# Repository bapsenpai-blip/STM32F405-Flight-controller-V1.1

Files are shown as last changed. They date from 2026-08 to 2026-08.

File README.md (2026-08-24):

# STM32F405-Flight-controller-V1.1
After the freaking horrible v1, I have changed a lot to improve my FC as much as possible.
RealFCv1 1
RealFCv1 1-back

### Changes from the V1
- Remove the SD card slot (took too much space). Using a blackbox instead.
- Remove 1 USB-C connector for ESP32. Now using an usb-mux + slide switch to choose which MCU is connected.
- Cleaner layout, board size changed from freaking big to 50x50mm (30.5x30.5 mounting hole).

### Components
- STM32F405RGT6: doing the basic things of an FC (calculate angles, PID, motor mixer,...)
- ESP32 S3 - WROOM 02: using DroneBrigde method for affordable Telemetry (I have no money to buy an $60 MAVLink Telemetry module)
- 8MHz Crystals from China: 10pF CLoad
- IMU: ICM-20602
- Barometer: BMP280
- Flash Memory: W25Q128JVS (16MB SPI Flash for Blackbox logging)
- USB-C Receptable 2.0 16 pins
- FSUSB42MUX: combining with a slideswitch to change the USB signal to desired MCU.
- Power supply: I'm gonna use an external Buck Converter, because I have no idea about power electronics
- USBLC6-2SC6: ESD protection for USB-C
- 2 AP2112K-3.3Vs: one for STM32 and other main components, one for only ESP32 (ESP32 consumes a lot of current when using Wi-fi/BLE)
- 2 SS14 Diodes: preventing reverse currents
- Resistors and capacitors: based on the recommendation of components' datasheets.

### Pin Mapping & Peripheral Connections

| Peripheral / Interface | Signal Name | MCU Pin | Description / Target |
| :--- | :--- | :--- | :--- |
| **IMU (ICM-20602)** | SPI2_NSS / SCK / MISO / MOSI | `PB12` / `PB13` / `PB14` / `PB15` | SPI Sensor Bus |
| | IMU_DDRY | `PC6` | EXTI Data Ready Interrupt |
| **Blackbox (W25Q128)** | SPI1_NSS / SCK / MISO / MOSI | `PA4` / `PA5` / `PA6` / `PA7` | 16MB SPI NOR Flash |
| **Barometer (BMP280)** | I2C1_SCL / I2C1_SDA | `PB8` / `PB9` | Internal Baro (4.7kΩ pull-ups) |
| **Motors (DSHOT)** | DSHOT_CH1 / CH2 | `PB4` / `PB5` | TIM3_CH1, TIM3_CH2 (to J3 ESC) |
| | DSHOT_CH3 / CH4 | `PB6` / `PB7` | TIM4_CH1, TIM4_CH4 (to J3 ESC) |
| **Telemetry (ESP32-S3)** | UART3_TX / UART3_RX | `PB10` / `PB11` | DroneBridge Telemetry link |
| **RC Receiver (J4)** | UART1_TX / UART1_RX | `PA9` / `PA10` | Serial RX (CRSF / SBUS / IBUS) |
| **GPS / Ext Sensor (J5)** | UART2_TX / UART2_RX | `PA2` / `PA3` | External GPS Serial Port |
| | I2C1_SCL / I2C1_SDA | `PB8` / `PB9` | External Compass / Sensor Bus |
| **ESC Telemetry (J3)** | UART4_RX | `PA1` | ESC Telemetry feedback |
| **Current / Voltage Sensing**| ADC1_IN14 (CURR) | `PC4` | Current sensor via 1kΩ / 100nF filter |
| | ADC1_IN15 (VBAT) | `PC5` | Battery voltage via 10:1 divider (11x) |
| **Status LEDs** | STAT_LED1 / LED2 / LED3 | `PC14` / `PB3` / `PC13` | Debug & status indicators |
| **USB & Debug (J7)** | S_D- / S_D+ | `PA11` / `PA12` | USB FS (via FSUSB42 MUX) |
| | SWDIO / SWCLK | `PA13` / `PA14` | SWD Debug port |

### Status & Firmware
- [x] Hardware verification: Validated on a custom STM32F405 breakout board (SPI, I2C, UART peripherals verified and working stably).
- [x] V1.1 PCB design & layout completed (ready for manufacturing/bring-up).
- [ ] Bring-up V1.1 integrated board (test power rails, USB mux swiSching, and onboard sensors).
- [ ] Port and configure open-source flight firmware (Betaflight / INAV / ArduPilot target).
- [ ] Bring-up ESP32-CS DroneBridge telemetry link.
- [ ] Bench test with 4-in-1 ESC (DShot) & maiden flight test.

**Firmware & Tools:** 
- Open-source flight controller firmware (target bring-up)
- ESP-IDF / DroneBridge for ESP32-S3
- VS Code - PlatformIO for low-level validation & debugging

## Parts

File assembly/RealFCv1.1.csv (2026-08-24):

Reference | Qty | Value | DNP | Exclude from BOM | Exclude from Board | Footprint | Datasheet
+VIN_BEC1,-VIN_BEC1 | 2 | TestPoint |  |  |  | TestPoint:TestPoint_THTPad_3.0x3.0mm_Drill1.5mm
C1,C2,C3,C4,C5,C7,C8,C14,C18,C20,C21,C22,C23,C24,C29,C30,C31,C32 | 18 | 100nF |  |  |  | Capacitor_SMD:C_0402_1005Metric_Pad0.74x0.62mm_HandSolder
C9,C10 | 2 | 12pF |  |  |  | Capacitor_SMD:C_0402_1005Metric_Pad0.74x0.62mm_HandSolder
C11,C12,C15 | 3 | 2.2uF |  |  |  | Capacitor_SMD:C_0402_1005Metric_Pad0.74x0.62mm_HandSolder
C13,C16,C25,C26 | 4 | 1uF |  |  |  | Capacitor_SMD:C_0402_1005Metric_Pad0.74x0.62mm_HandSolder
C17 | 1 | 4.7uF |  |  |  | Capacitor_SMD:C_0805_2012Metric_Pad1.18x1.45mm_HandSolder
C19 | 1 | 10nF |  |  |  | Capacitor_SMD:C_0402_1005Metric_Pad0.74x0.62mm_HandSolder
C27 | 1 | 4.7u |  |  |  | Capacitor_SMD:C_0805_2012Metric_Pad1.18x1.45mm_HandSolder
C28 | 1 | 10uF |  |  |  | Capacitor_SMD:C_0603_1608Metric_Pad1.08x0.95mm_HandSolder
D2,D5,D8,D12 | 4 | LED_RED |  |  |  | LED_SMD:LED_0402_1005Metric_Pad0.77x0.64mm_HandSolder
D3,D4 | 2 | SS14 |  |  |  | Diode_SMD:D_SMA | https://www.vishay.com/docs/88746/ss12.pdf
J1 | 1 | USB_C_Receptacle_USB2.0_14P |  |  |  | Connector_USB:USB_C_Receptacle_HRO_TYPE-C-31-M-12 | https://www.usb.org/sites/default/files/documents/usb_type-c.zip
J3 | 1 | Conn_01x08_Socket |  |  |  | Connector_JST:JST_SH_SM08B-SRSS-TB_1x08-1MP_P1.00mm_Horizontal
J4 | 1 | Conn_01x04_Socket |  |  |  | Connector_JST:JST_SH_SM04B-SRSS-TB_1x04-1MP_P1.00mm_Horizontal
J5 | 1 | Conn_01x06_Socket |  |  |  | Connector_JST:JST_SH_SM06B-SRSS-TB_1x06-1MP_P1.00mm_Horizontal
J7 | 1 | Conn_01x04_Socket |  |  |  | Connector_PinHeader_2.54mm:PinHeader_1x04_P2.54mm_Vertical
R2,R3,R17,R24,R25,R26 | 6 | 10kR |  |  |  | Resistor_SMD:R_0402_1005Metric_Pad0.72x0.64mm_HandSolder
R4,R5 | 2 | 5.1kR |  |  |  | Resistor_SMD:R_0402_1005Metric_Pad0.72x0.64mm_HandSolder
R7,R8,R14,R15,R16,R29 | 6 | 1kR |  |  |  | Resistor_SMD:R_0402_1005Metric_Pad0.72x0.64mm_HandSolder
R10,R11,R18,R19,R20 | 5 | 4.7kR |  |  |  | Resistor_SMD:R_0402_1005Metric_Pad0.72x0.64mm_HandSolder
SW1,SW2 | 2 | SW_Push |  |  |  | Button_Switch_SMD:SW_Push_1P1T-SH_NO_CK_KMR2xxG
SW5 | 1 | SW_SPDT_312 |  |  |  | Button_Switch_SMD:SW_SPDT_PCM12
TP1,TP2,TP3,TP4 | 4 | TestPoint |  |  |  | TestPoint:TestPoint_Pad_D1.0mm
U1 | 1 | STM32F405RGTx |  |  |  | Package_QFP:LQFP-64_10x10mm_P0.5mm | https://www.st.com/resource/en/datasheet/stm32f405rg.pdf
U2,U7 | 2 | AP2112K-3.3 |  |  |  | Package_TO_SOT_SMD:SOT-23-5_HandSoldering | https://www.diodes.com/assets/Datasheets/AP2112.pdf
U3 | 1 | USBLC6-2SC6 |  |  |  | Package_TO_SOT_SMD:SOT-23-6_Handsoldering | https://www.st.com/resource/en/datasheet/usblc6-2.pdf
U4 | 1 | ICM-20602 |  |  |  | Package_LGA:LGA-16_3x3mm_P0.5mm_LayoutBorder3x5y | http://www.invensense.com/wp-content/uploads/2016/10/DS-000176-ICM-20602-v1.0.pdf
U5 | 1 | BMP280 |  |  |  | Package_LGA:Bosch_LGA-8_2x2.5mm_P0.65mm_ClockwisePinNumbering | https://ae-bst.resource.bosch.com/media/_tech/media/datasheets/BST-BMP280-DS001.pdf
U6 | 1 | ESP32-C3-WROOM-02 |  |  |  | RF_Module:ESP32-C3-WROOM-02 | https://www.espressif.com/sites/default/files/documentation/esp32-c3-wroom-02_datasheet_en.pdf
U9 | 1 | W25Q128JVS |  |  |  | Package_SO:SOIC-8_5.3x5.3mm_P1.27mm | https://www.winbond.com/resource-files/w25q128jv_dtr%20revc%2003272018%20plus.pdf
U10 | 1 | FSUSB42MUX |  |  |  | Package_SO:MSOP-10_3x3mm_P0.5mm | https://www.onsemi.com/pub/Collateral/FSUSB42-D.PDF
Y1 | 1 | Crystal_GND24 |  |  |  | Crystal:Crystal_SMD_3225-4Pin_3.2x2.5mm_HandSoldering

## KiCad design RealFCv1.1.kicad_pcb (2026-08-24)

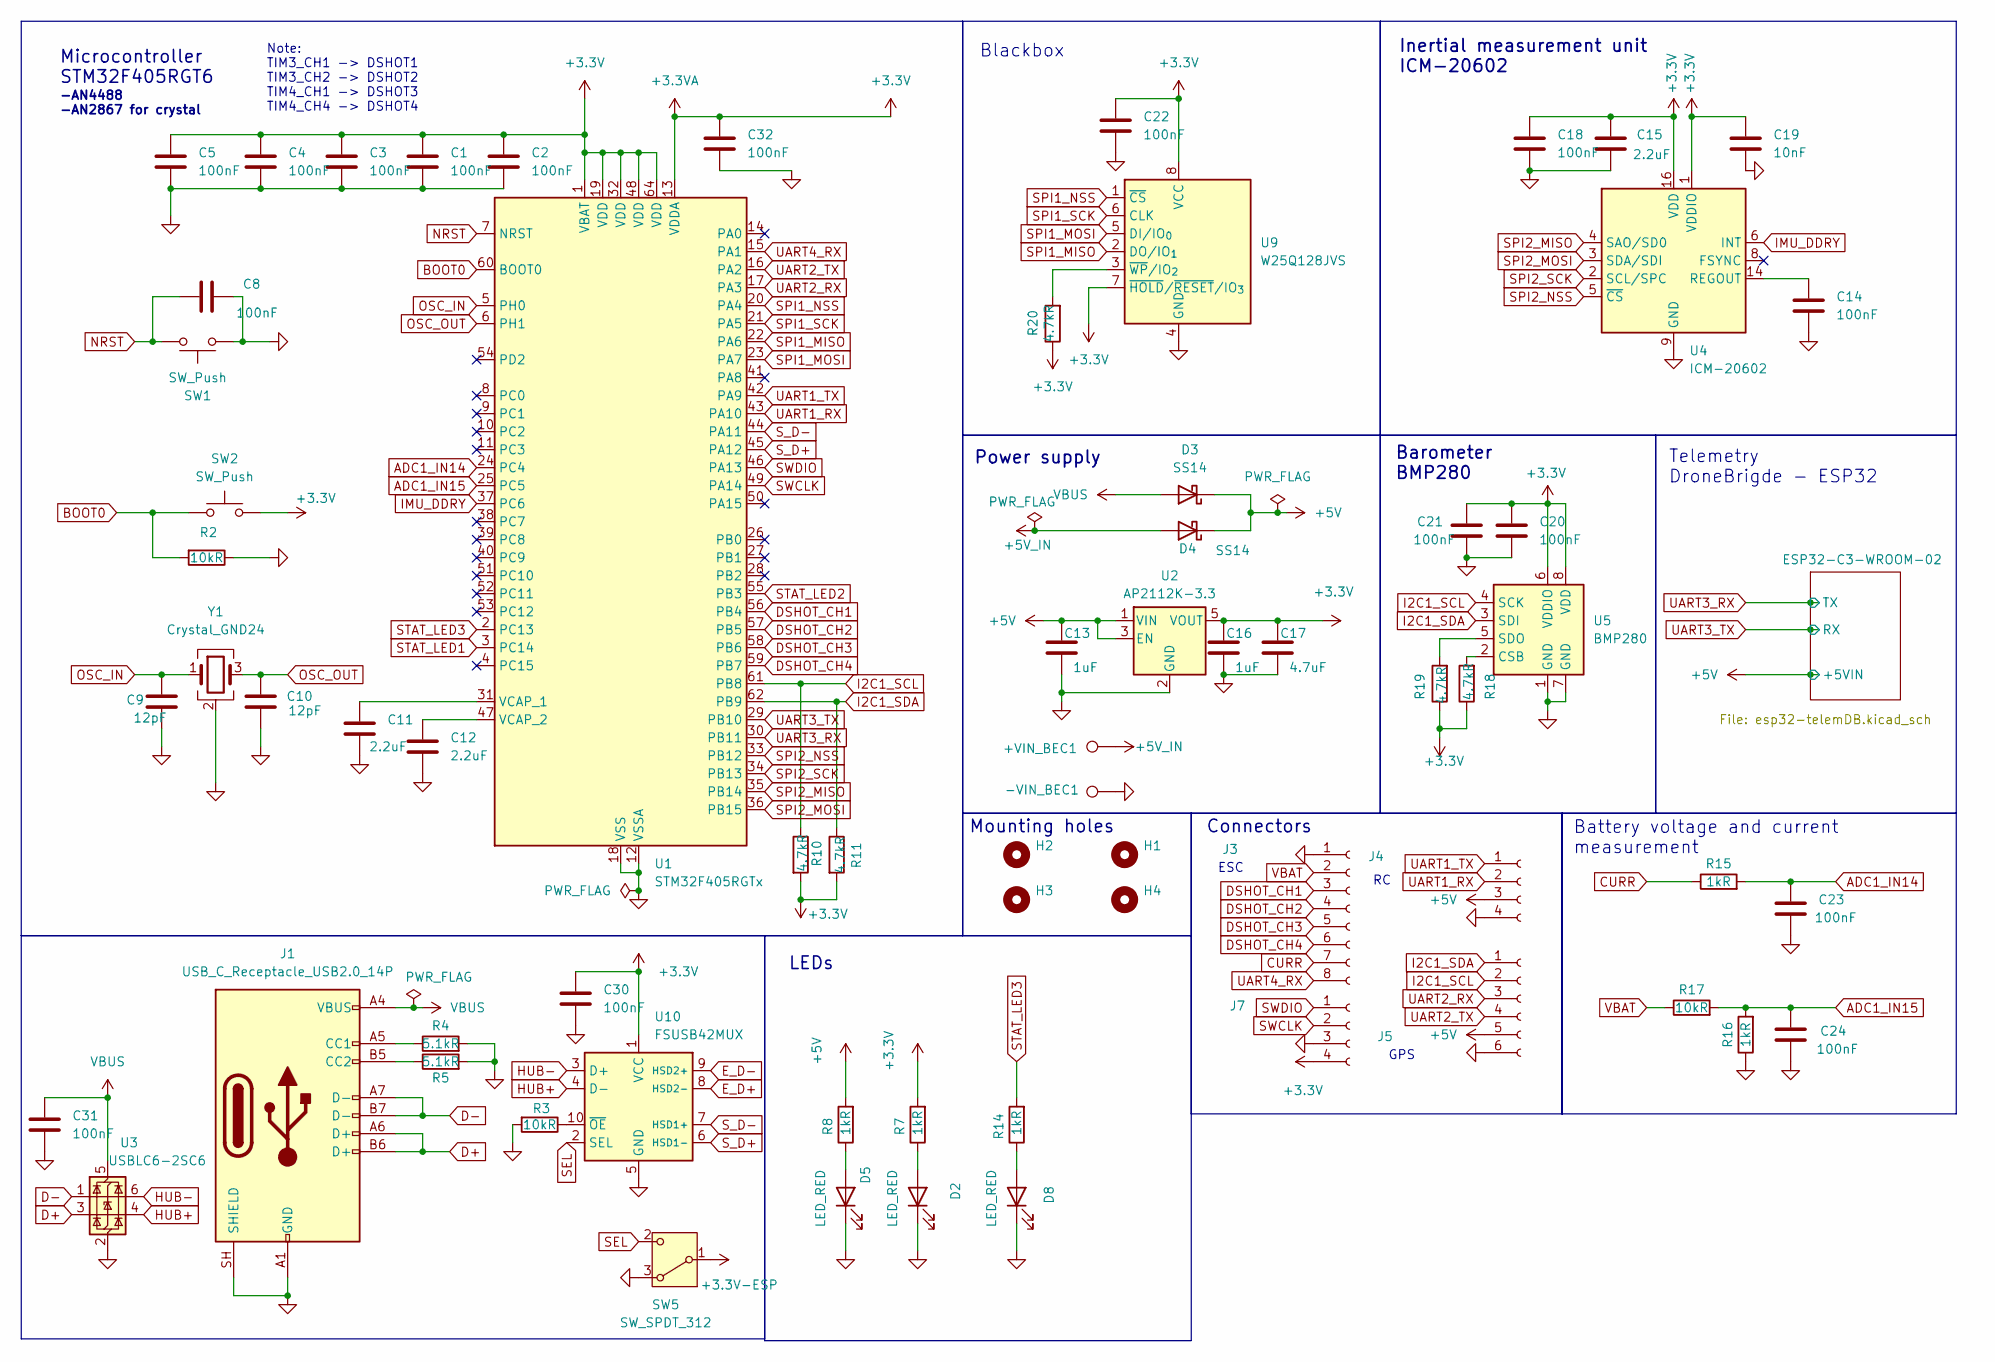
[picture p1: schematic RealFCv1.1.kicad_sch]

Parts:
+VIN_BEC1: TestPoint; TestPoint_THTPad_3.0x3.0mm_Drill1.5mm
-VIN_BEC1: TestPoint; TestPoint_THTPad_3.0x3.0mm_Drill1.5mm
C1, C2, C3, C4, C5, C8, C14, C18, C20, C21, C22, C23, C24, C30, C31, C32: 100nF; C_0402_1005Metric_Pad0.74x0.62mm_HandSolder
C9, C10: 12pF; C_0402_1005Metric_Pad0.74x0.62mm_HandSolder
C11, C12, C15: 2.2uF; C_0402_1005Metric_Pad0.74x0.62mm_HandSolder
C13, C16: 1uF; C_0402_1005Metric_Pad0.74x0.62mm_HandSolder
C17: 4.7uF; C_0805_2012Metric_Pad1.18x1.45mm_HandSolder
C19: 10nF; C_0402_1005Metric_Pad0.74x0.62mm_HandSolder
D2, D5, D8: LED_RED; LED_0402_1005Metric_Pad0.77x0.64mm_HandSolder
D3, D4: SS14; D_SMA
H1, H2, H3, H4: MountingHole; MountingHole_3.2mm_M3
J1: USB_C_Receptacle_USB2.0_14P; USB_C_Receptacle_HRO_TYPE-C-31-M-12
J3: Conn_01x08_Socket; JST_SH_SM08B-SRSS-TB_1x08-1MP_P1.00mm_Horizontal
J4: Conn_01x04_Socket; JST_SH_SM04B-SRSS-TB_1x04-1MP_P1.00mm_Horizontal
J5: Conn_01x06_Socket; JST_SH_SM06B-SRSS-TB_1x06-1MP_P1.00mm_Horizontal
J7: Conn_01x04_Socket; PinHeader_1x04_P2.54mm_Vertical
R2, R3, R17: 10kR; R_0402_1005Metric_Pad0.72x0.64mm_HandSolder
R4, R5: 5.1kR; R_0402_1005Metric_Pad0.72x0.64mm_HandSolder
R7, R8, R14, R15, R16: 1kR; R_0402_1005Metric_Pad0.72x0.64mm_HandSolder
R10, R11, R18, R19, R20: 4.7kR; R_0402_1005Metric_Pad0.72x0.64mm_HandSolder
SW1, SW2: SW_Push; SW_Push_1P1T-SH_NO_CK_KMR2xxG
SW5: SW_SPDT_312; SW_SPDT_PCM12
U1: STM32F405RGTx; LQFP-64_10x10mm_P0.5mm
U2: AP2112K-3.3; SOT-23-5_HandSoldering
U3: USBLC6-2SC6; SOT-23-6_Handsoldering
U4: ICM-20602; LGA-16_3x3mm_P0.5mm_LayoutBorder3x5y
U5: BMP280; Bosch_LGA-8_2x2.5mm_P0.65mm_ClockwisePinNumbering
U9: W25Q128JVS; SOIC-8_5.3x5.3mm_P1.27mm
U10: FSUSB42MUX; MSOP-10_3x3mm_P0.5mm
Y1: Crystal_GND24; Crystal_SMD_3225-4Pin_3.2x2.5mm_HandSoldering

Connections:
+3.3V: C1.1, C2.1, C3.1, C4.1, C5.1, C15.1, C16.1, C17.1, C18.1, C19.1, C20.1, C21.1, C22.2, C30.2, C32.1, J7.4, R7.2, R10.2, R11.2, R18.1, R19.1, R20.1, SW2.2, U1.1 (VBAT), U1.13 (VDDA), U1.19 (VDD), U1.32 (VDD), U1.48 (VDD), U1.64 (VDD), U2.5 (VOUT), U4.1 (VDDIO), U4.16 (VDD), U5.6 (VDDIO), U5.8 (VDD), U9.7 (~HOLD/~RESET/IO_{3}), U9.8 (VCC), U10.1 (VCC)
+3.3V-ESP: SW5.1 (B); also elsewhere on the board
+5V: C13.1, D3.1 (K), D4.1 (K), J4.3, J5.5, R8.2, U2.1 (VIN), U2.3 (EN); also elsewhere on the board
+5V_IN: +VIN_BEC1.1 (1_1), D4.2 (A)
ADC1_IN14: C23.1, R15.2, U1.24 (PC4)
ADC1_IN15: C24.1, R16.2, R17.2, U1.25 (PC5)
BOOT0: R2.2, SW2.1, U1.60 (BOOT0)
CURR: J3.7, R15.1
D+: J1.A6 (D+), J1.B6 (D+), U3.3 (I/O2)
D-: J1.A7 (D-), J1.B7 (D-), U3.1 (I/O1)
DSHOT_CH1: J3.3, U1.56 (PB4)
DSHOT_CH2: J3.4, U1.57 (PB5)
DSHOT_CH3: J3.5, U1.58 (PB6)
DSHOT_CH4: J3.6, U1.59 (PB7)
E_D+: U10.8 (HSD2-); also elsewhere on the board
E_D-: U10.9 (HSD2+); also elsewhere on the board
GND: -VIN_BEC1.1 (1_1), C1.2, C2.2, C3.2, C4.2, C5.2, C8.2, C9.2, C10.2, C11.2, C12.2, C13.2, C14.2, C15.2, C16.2, C17.2, C18.2, C19.2, C20.2, C21.2, C22.1, C23.2, C24.2, C30.1, C31.1, C32.2, D2.1 (K), D5.1 (K), D8.1 (K), J1.A1 (GND), J1.A12 (GND), J1.B1 (GND), J1.B12 (GND), J1.SH (SHIELD), J3.1, J4.4, J5.6, J7.3, R2.1, R3.2, R4.2, R5.2, R16.1, SW1.1, SW5.3 (A), U1.12 (VSSA), U1.18 (VSS), U1.63 (VSS), U2.2 (GND), U3.2 (GND), U4.9 (GND), U4.10 (GND), U4.11 (GND), U4.12 (GND), U4.13 (GND), U4.15 (GND), U5.1 (GND), U5.7 (GND), U9.4 (GND), U10.5 (GND), Y1.2 (G), Y1.4 (G); also elsewhere on the board
HUB+: U3.4 (I/O2), U10.4 (D-)
HUB-: U3.6 (I/O1), U10.3 (D+)
I2C1_SCL: J5.2, R10.1, U1.61 (PB8), U5.4 (SCK)
I2C1_SDA: J5.1, R11.1, U1.62 (PB9), U5.3 (SDI)
IMU_DDRY: U1.37 (PC6), U4.6 (INT)
NRST: C8.1, SW1.2, U1.7 (NRST)
unnamed: D2.2 (A), R7.1
unnamed: D5.2 (A), R8.1
unnamed: D8.2 (A), R14.1
unnamed: J1.A5 (CC1), R4.1
unnamed: J1.B5 (CC2), R5.1
unnamed: C11.1, U1.31 (VCAP_1)
unnamed: C12.1, U1.47 (VCAP_2)
unnamed: C14.1, U4.14 (REGOUT)
unnamed: R18.2, U5.2 (CSB)
unnamed: R19.2, U5.5 (SDO)
unnamed: R20.2, U9.3 (~WP/IO_{2})
unnamed: R3.1, U10.10 (~OE)
OSC_IN: C9.1, U1.5 (PH0), Y1.1
OSC_OUT: C10.1, U1.6 (PH1), Y1.3
SEL: SW5.2 (C), U10.2 (SEL)
SPI1_MISO: U1.22 (PA6), U9.2 (DO/IO_{1})
SPI1_MOSI: U1.23 (PA7), U9.5 (DI/IO_{0})
SPI1_NSS: U1.20 (PA4), U9.1 (~CS)
SPI1_SCK: U1.21 (PA5), U9.6 (CLK)
SPI2_MISO: U1.35 (PB14), U4.4 (SAO/SD0)
SPI2_MOSI: U1.36 (PB15), U4.3 (SDA/SDI)
SPI2_NSS: U1.33 (PB12), U4.5 (~CS)
SPI2_SCK: U1.34 (PB13), U4.2 (SCL/SPC)
STAT_LED1: U1.3 (PC14)
STAT_LED2: U1.55 (PB3)
STAT_LED3: R14.2, U1.2 (PC13)
SWCLK: J7.2, U1.49 (PA14)
SWDIO: J7.1, U1.46 (PA13)
S_D+: U1.45 (PA12), U10.6 (HSD1-)
S_D-: U1.44 (PA11), U10.7 (HSD1+)
UART1_RX: J4.2, U1.43 (PA10)
UART1_TX: J4.1, U1.42 (PA9)
UART2_RX: J5.3, U1.17 (PA3)
UART2_TX: J5.4, U1.16 (PA2)
UART3_RX: U1.30 (PB11); also elsewhere on the board
UART3_TX: U1.29 (PB10); also elsewhere on the board
UART4_RX: J3.8, U1.15 (PA1)
VBAT: J3.2, R17.1
VBUS: C31.2, D3.2 (A), J1.A4 (VBUS), J1.A9 (VBUS), J1.B4 (VBUS), J1.B9 (VBUS), U3.5 (VBUS)

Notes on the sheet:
Microcontroller STM32F405RGT6
Note: TIM3_CH1 -> DSHOT1 TIM3_CH2 -> DSHOT2 TIM4_CH1 -> DSHOT3 TIM4_CH4 -> DSHOT4
ESC
Telemetry DroneBrigde - ESP32
Inertial measurement unit ICM-20602
GPS
Barometer BMP280
Power supply
LEDs
Blackbox
Battery voltage and current measurement
Mounting holes
Connectors
-AN4488 -AN2867 for crystal

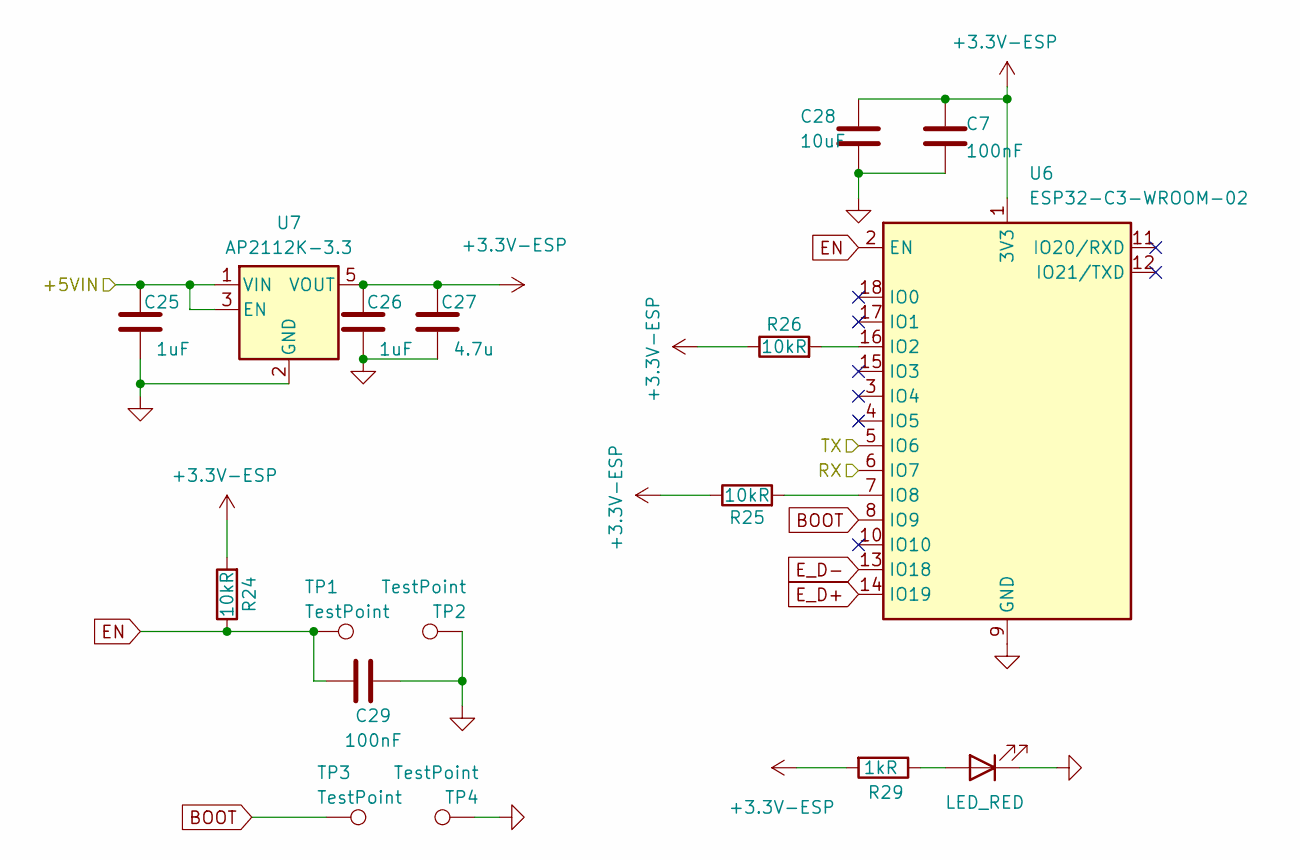
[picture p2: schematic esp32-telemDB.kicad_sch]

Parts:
C7, C29: 100nF; C_0402_1005Metric_Pad0.74x0.62mm_HandSolder
C25, C26: 1uF; C_0402_1005Metric_Pad0.74x0.62mm_HandSolder
C27: 4.7u; C_0805_2012Metric_Pad1.18x1.45mm_HandSolder
C28: 10uF; C_0603_1608Metric_Pad1.08x0.95mm_HandSolder
D12: LED_RED; LED_0402_1005Metric_Pad0.77x0.64mm_HandSolder
R24, R25, R26: 10kR; R_0402_1005Metric_Pad0.72x0.64mm_HandSolder
R29: 1kR; R_0402_1005Metric_Pad0.72x0.64mm_HandSolder
TP1, TP2, TP3, TP4: TestPoint; TestPoint_Pad_D1.0mm
U6: ESP32-C3-WROOM-02
U7: AP2112K-3.3; SOT-23-5_HandSoldering

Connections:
+3.3V-ESP: C7.1, C26.1, C27.1, C28.1, R24.2, R25.1, R26.1, R29.2, U6.1 (3V3), U7.5 (VOUT); also elsewhere on the board
+5V: C25.1, U7.1 (VIN), U7.3 (EN); also elsewhere on the board
BOOT: TP3.1 (1_1), U6.8 (IO9)
EN: C29.1, R24.1, TP1.1 (1_1), U6.2 (EN)
E_D+: U6.14 (IO19); also elsewhere on the board
E_D-: U6.13 (IO18); also elsewhere on the board
GND: C7.2, C25.2, C26.2, C27.2, C28.2, C29.2, D12.1 (K), TP2.1 (1_1), TP4.1 (1_1), U6.9 (GND), U6.19 (GND), U7.2 (GND); also elsewhere on the board
unnamed: D12.2 (A), R29.1
unnamed: R26.2, U6.16 (IO2)
unnamed: R25.2, U6.7 (IO8)
UART3_RX: U6.5 (IO6); also elsewhere on the board
UART3_TX: U6.6 (IO7); also elsewhere on the board

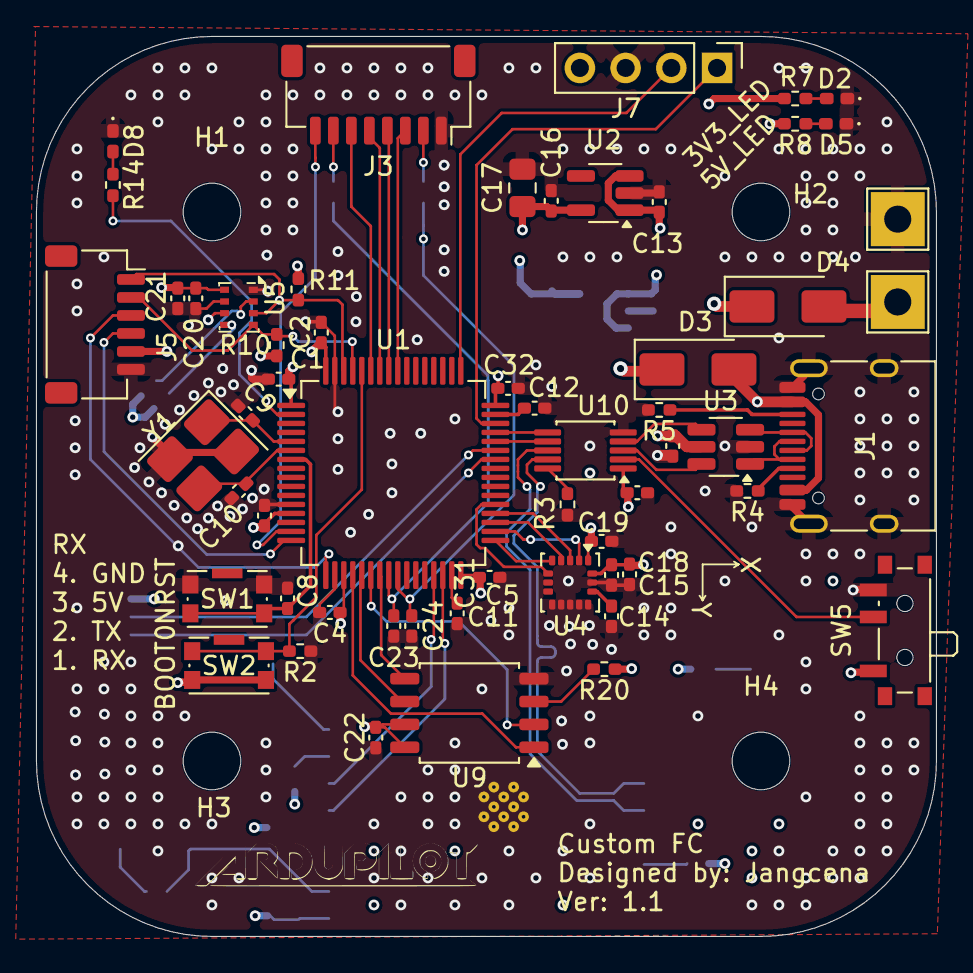
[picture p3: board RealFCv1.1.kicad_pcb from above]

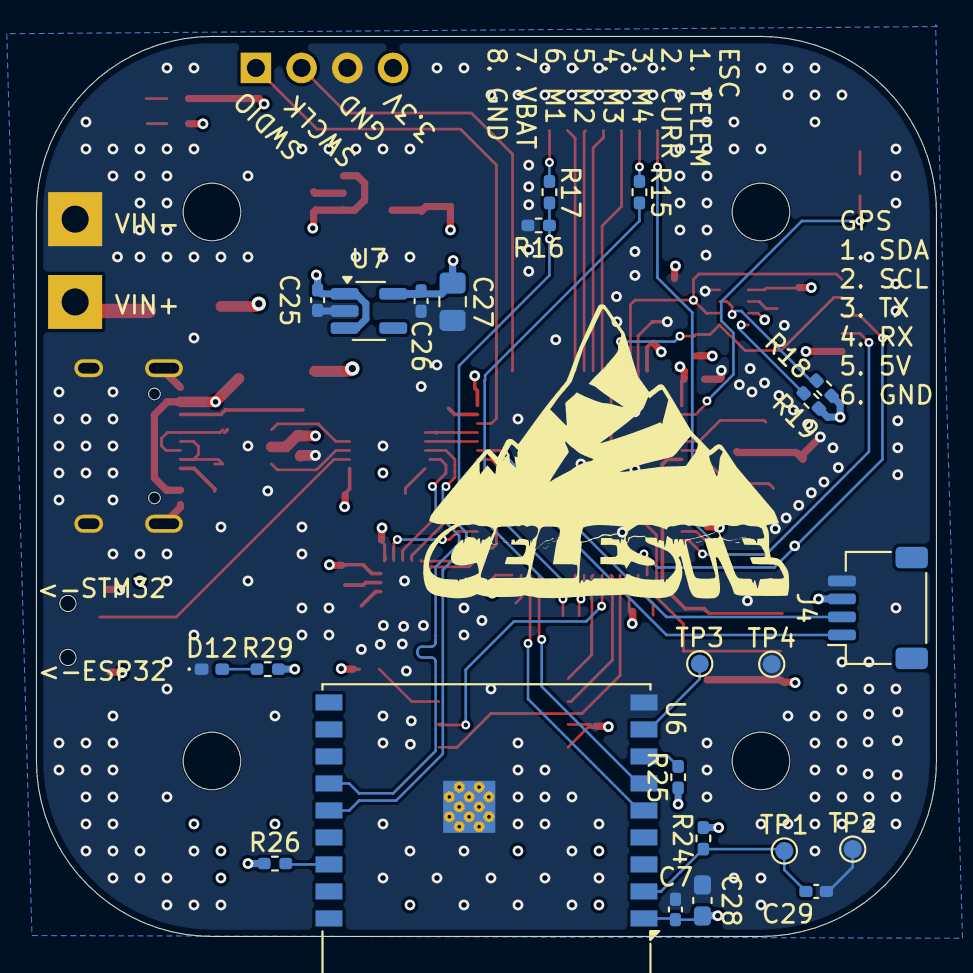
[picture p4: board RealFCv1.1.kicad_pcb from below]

Board: 4 copper layers, 50.0 x 50.0 mm, 84 parts (23 on the bottom side), 65 nets.
